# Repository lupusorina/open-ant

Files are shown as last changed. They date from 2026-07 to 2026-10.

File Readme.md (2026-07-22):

# Physical Ant

<p align="center">
  Ant walking demo
</p>
<p align="center">
  Video of a learned behaviour directly on hardware.
</p>

## Hardware.

The hardware is designed to be easy to build and use:
- single computer operation via USB, Python only, minimal dependencies (no embedded firmware / OS, networking, ROS...)
- no battery: continuous operation with wall adapter
- all COTS parts + 3D printed parts
- no soldering required
- no special tools required (only the standard hex drivers for M2, M2.5, and M3 screws which are 1.5mm, 2.0mm, and 2.5mm, respectively)

## Assembly video

[Watch the assembly video](https://www.youtube.com/watch?v=9aowd2JxAnE)

### Specs.

- hip range +/- 45deg
- knee range +/- 70deg

### Physical Ant platform, learning arena, and system overview.

<p align="center">
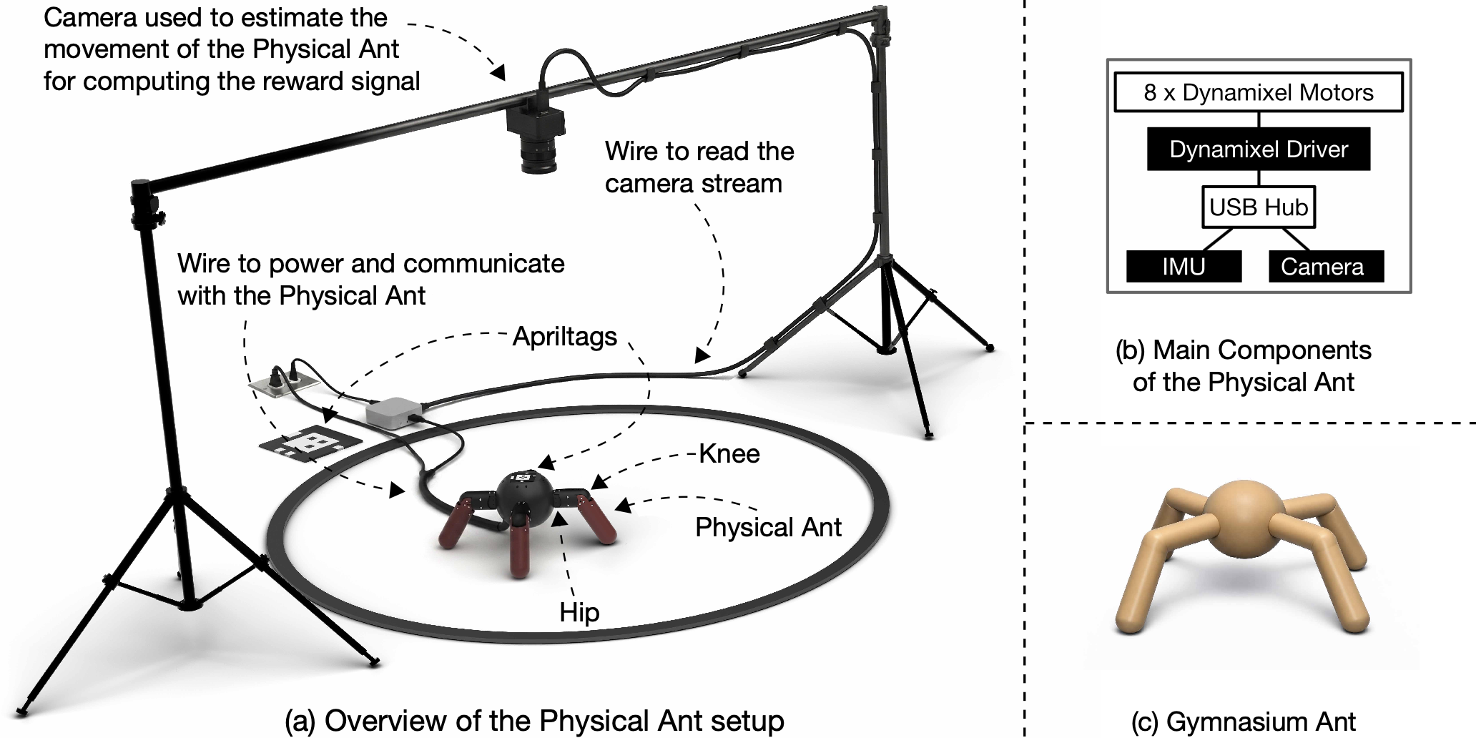
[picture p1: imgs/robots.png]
Robot setup
  
</p>
<p align="center">
  <b>Physical Ant platform, learning arena, and system overview.</b> (a) An overhead webcam tracks the fiducial markers to compute reward signals for locomotion tasks as well as the heading vector of the ant. The robot is connected by cables to AC power and to an external computer where the agent is running. (b) The main components of the Physical Ant. (c) The Gymnasium Ant, which was the inspiration for the Physical Ant.
</p>

#### Bill of Materials.

| Part Name | Quantity | Notes | Link | Price (March 2026) |
|---|---|---|---|---|
| Dynamixel XM430-W350-T | 4 | Main actuators  (incl.  180mm cable) | [Robotis](https://www.robotis.us/dynamixel-xm430-w350-t/) | $1241.56 (310.39 each) |
| Dynamixel XC430-W240-T | 4 | Main actuators  (incl.  180mm cable) | [Robotis](https://robotis.us/dynamixel-xc430-w240-t/) | $551.56 ($137.89 each) |
| HN11-I101 Set | 4 | Idler bearing | [Robotis](https://www.robotis.us/hn11-i101-set/) | $32.20 (8.05 each) |
| HN12-I101 Set | 4 | Idler bearing | [Robotis](https://www.robotis.us/hn12-i101-set/) | $81.88 (20.47 each)  |
| U2D2 Starter Set | 1 | Includes: USB to Dynamixel, Power Hub Board, 12V 5A Power Supply | [Robotis](https://www.robotis.us/dynamixel-starter-set-us/) | $68.66 |
| Kakute H7 Mini / TBS Lucid Freestyle mini | 1 | Quadcopter flight controller used as IMU (Any Betaflight compatible autopilot with 20x20mm mounts will work) | [getfpv](https://www.getfpv.com/tbs-lucid-freestyle-f4-mini-flight-controller-icm42688-20x20.html) | $51.99 |
| Cable Matters Ultra Mini USB Hub | 1 | 4 Port USB Hub | [Amazon](https://www.amazon.com/dp/B00PHPWLPA/) | $15.49 |
| Short USB-A to USB-C Cable | 1 | For autopilot (IMU) | [Amazon](https://www.amazon.com/dp/B01ASXBY62) | $11.96 |
| Short USB-A to micro-USB cable | 1 | For Dynamixel U2D2 | [Amazon](https://www.amazon.com/dp/B08BZD66H4?th=1) | $6.99 |
| USB-A extension cable | 1 | As tether for the robot | [Amazon](https://www.amazon.com/dp/B07ZV6FHWF/) | $5.99 |
| 12V 8A AC to DC Converter Power Adapter | 1 | Power adapter for the robot, to replace the one from the U2D2 starter kit | [Amazon](https://www.amazon.com/dp/B0F24DZ2SB?ref=ppx_yo2ov_dt_b_fed_asin_title&th=1) | $17.09 |
| Screw M2x4mm with socket head | 80 | Output shaft, 8 per motor, 3D print assembly | [McMaster](https://www.mcmaster.com/91290A012/) | $18.48 (pack of 100) |
| M2 washer | 64 | Output shaft | [McMaster](https://www.mcmaster.com/93475A195/)  | $1.78 (pack of 100) |
| Screw M2.5x16mm with socket head | 32 | motor mount, 4 per motor | [McMaster](https://www.mcmaster.com/91290a106/) | $12.81 (pack of 50)  |
| Screw M3x8mm with socket head | 6 | U2D2 power board mount + IMU | [McMaster](https://www.mcmaster.com/91290A113/) | $12.82 (pack of 100) |
| Nut M2 | 16 | 3D print assembly 4 per leg | [McMaster](https://www.mcmaster.com/91828A111/) | $6.75 (pack of 100)  |
| Nut M3 | 2 | U2D2 power board mount | [McMaster](https://www.mcmaster.com/91828A211/) | $5.2 (pack of 100)  |
| On-board camera and top-down camera for tracking | 2 | Logitech Brio 101 | [Logitech](https://www.logitech.com/en-us/shop/p/brio-100-webcam) | $79.98 (39.99 each) |
| 3D Printed Parts | - | STL files in `hardware/rev3`. Print all `leg` files 4x, others 1x. | - | - |
| **Total** | | | | **$2223.19** |

We recommend adding a heat sink to the knee actuators, for example this [one](https://www.amazon.com/dp/B08HLZWKYN?ref_=ppx_hzsearch_conn_dt_b_fed_asin_title_1&th=1)

### Dynamixel Setup (before assembling the robot!)

The Dynamixels should be configured to 1Mbaud and have their IDs changed to the following:

| Motor Position | Motor ID |
|---|---|
| Rear Right Hip | 10 |
| Rear Right Knee | 11 |
| Front Right Hip | 20 |
| Front Right Knee | 21 |
| Front Left Hip | 30 |
| Front Left Knee | 31 |
| Rear Left Hip | 40 |
| Rear Left Knee | 41 |

Use the following script to change the IDs of the motors, connecting one at a time.
```
python3 embodied_ant_env/dynamixel_change_id.py /dev/tty.usbserial-XXXXXXX <NEW_ID> 57600
```

When done, the following command will change the baudrate of all connected motors on the port to 1Mbaud.
```
python3 embodied_ant_env/dynamixel_change_baud.py /dev/tty.usbserial-XXXXXXX 1000000
```

## Software Setup

Create a virtual environment and install the dependencies. (python >= 3.10)
```
python3.12 -m venv ant_env
source ant_env/bin/activate
pip install -r requirements.txt
```

To create a new config file, run:
```
python3 embodied_ant_env/make_ant_config.py /dev/tty.usbserial-XXXXXXX <APRIL_TAG_ID>
```
which will create a new config file `ant<APRIL_TAG_ID>.json` in the current directory.

Next, edit the config file to specify imu port, camera id and fov.

### Possible signals

- Joint position
- Joint velocity
- Body angular rate
- Inertial up in body
- Commanded velocity in x and y

For reward: position of the body in x and y, and the angle of the body.

## Run the simulation

```
cd sim
python3 ant_mujoco.py
```

## Run SAC

for simulation:
```
cd agents/sac/
./run.sh sim
```

for hardware:
```
cd agents/sac/
./run.sh hw
```

## Run SARSA

for simulation:
```
cd agents/sarsa/
./run.sh sim
```

for hardware:
```
cd agents/sarsa/
./run.sh hw
```

## Frequently Asked Questions (FAQ)

### Q: The position of the ant flickers. What should I do?

The fiducial system is designed to be quite robust. If you encounter problems, make sure the markers are clearly visible and the camera exposure is configured properly (you can adjust exposure using LogiTune). 
Here are some suggestions:
* Depending on your environment, you may need to disable auto-exposure for more consistent detection.
* For the best performance, you should have the camera looking down at the playground.
* The origin marker should be mounted flat. Any warping can cause issues.
* Make sure to plot all system inputs and outputs to verify that the signals are clean. Learning from noisy or faulty signals can lead to poor results.

### Q: What’s the recommended way to specify a /dev/ device path in a JSON file on Ubuntu?

Use the persistent device path, for example:
```
/dev/serial/by-id/YYY
```

### Q: Will the screws become loose over time due to vibrations?

Yes, it can happen. For this, it is recommended to use Loctite Threadlocker. Ensure you don't apply too much because it can leak under the motor head and cause clogging.

### Q: How can we increase the friction on the lower legs?

We recommend 3D printing socks out of TPU.

### Q: There might be intermittent communication dropout. How is this addressed?

During long duration run-time learning experiments, we observed intermittent, very short communication dropouts. 
The power connection was modified to connect directly to the screw terminals on the control board rather than using the barrel connector. This eliminated the voltage drops caused by vibration-induced intermittent contact during learning experiments.

## Misc

if git push fails when adding large (~10MB) commits, try:
```
git config --global http.postBuffer 1048576000
```

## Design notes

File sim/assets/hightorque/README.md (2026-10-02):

# High Torque Robotics Mini Pi+ Pro

23-DoF humanoid, 14.72 kg, 0.367 m standing base height.
Product page: https://www.hightorquerobotics.com/mini-pi

## Provenance

Supplied by High Torque as `PiPlus_S_12L8A0G2H1W_LSE_260611`
(`PiPlus_S_12L8A0G2H1W_LSE_260611_with_armature.xml` plus `meshes/`). The code
in the name is the joint census: 12 leg, 8 arm, 0 gripper, 2 head, 1 waist.
No licence file accompanied the drop.

## What changed from the vendor file

`mini_pi.xml` is the vendor MJCF with five edits, all mechanical:

1. **The scene came out.** The vendor file carries its own floor plane, light,
   skybox and `<visual>`/`<statistic>` block. `ArenaBuilder` supplies those, and
   a second ground plane z-fights with the arena's. They now live in
   `scene.xml`, which `<include>`s the robot — the layout `booster_t1/` uses.
2. **The six floating-base motors came out.** The vendor block drove
   `floating_base_joint` with an `fx fy fz tx ty tz` wrench. That is a test
   harness: a free-floating robot in an arena has no such actuator, and the six
   would show up as extra `ctrl` slots.
3. **`meshdir` is `meshes`,** not `../meshes/` — the meshes sit beside the file
   here, not one level up as they did in the drop.
4. **Motor `ctrlrange` was aligned to the joint's own `actuatorfrcrange`,** per
   joint, taking the smaller of the two. The vendor authored them
   inconsistently: legs ±20 N·m under a ±21 joint rating, the waist ±30 under
   ±16, the arms ±20 under ±10. MuJoCo enforces the joint rating regardless, so
   the pair disagreeing only hides the real budget. `assets/manifests/mini_pi.yaml`
   carries the same numbers as `torque_limits`.
5. **A `home` keyframe was added.** The vendor file has none; see below.
6. **The visual meshes were decimated** from 1.23 M triangles to 178 k. See
   below.

Quote characters in `class='leg_motor'` attributes were normalised to double
quotes, and the model was renamed from the part number to `mini_pi_plus_pro`.

## The `home` stance

A 0.25 rad symmetric crouch (hip pitch −0.25, knee +0.50, ankle pitch −0.25
keeps the sole flat) with the arms hanging but abducted 0.20 rad at the
shoulder roll, base at z = 0.367 so the soles rest on z = 0.

Vendor joint names carry the segment, not the axis: `*_thigh_joint` is hip yaw
(axis z) and `*_calf_joint` is the knee (axis y).

The abduction is not cosmetic. At the vendor's all-zero pose the 0.03 m hand
spheres on `*_wrist_link` sit ~0.1 mm inside the thigh cylinders; 0.05 rad of
shoulder roll clears them and 0.20 leaves margin. Nothing resets to the all-zero
pose in normal use — `MdpEnv` writes the manifest `default_pose` — so this is
recorded rather than worked around.

## Where the PD gains came from

High Torque ships no trained controller with the model, so unlike
`assets/manifests/t1.yaml` there is no vendor RL config to copy. The manifest
gains are the smallest round values that hold `home` for 10 s under gravity,
measured on this MJCF with `install_pd_servos` at the training sim settings
(`sim_dt` 0.02/3, 30 iterations, `implicitfast`):

| hip/knee kp | kd  | 10 s base z | knee sag | peak τ |
|---:|----:|---:|---:|---:|
| 60 | 3.0 | 0.086 (down at 1.7 s) | — | 100% |
| 80 | 3.5 | 0.366 | 0.031 rad | 14% |
| **100** | **3.5** | **0.366** | **0.022 rad** | **12%** |
| 150 | 4.0 | 0.367 | 0.013 rad | 11% |
| 200 | 5.0 | 0.367 | 0.010 rad | 10% |

Below kp 80 an open-loop PD hold topples backwards over the heels — a balance
failure, not a numerical one: the CoM starts 9 mm ahead of the ankles with
67 mm of rear margin and walks out of the support polygon as the hips and
ankles sag. kp 100 was taken because its 0.022 rad knee sag is already under
the 0.030 the T1 manifest accepted, and ±10% (the `randomize_pd_gains` band)
still stands.

The measurement agrees with the vendor precedent: T1's hips are 200 kp at a
45 N·m rating, i.e. 4.4 kp per N·m, which at this robot's 20 N·m would give 89.
Ankles use T1's softer ratio (2.5 kp per N·m → 50), and arms and head scale the
same way off their own ratings.

## Known gaps

- `head_yaw_joint` and `head_pitch_joint` carry no `class`, so they alone have
  `armature="0"` — the vendor gave every other joint a rotor inertia. Left as
  authored: at the manifest's kp 10 the head tracks to 0.008 rad and never
  approaches its 3.6 N·m limit, so nothing yet depends on filling it in.
- The 28 mesh geoms are visual only (`contype=0 conaffinity=0 density=0`); all
  collision is primitive boxes, cylinders and spheres.
- There is no separate hand body — the forearm ends in a fixed `*_wrist_link` —
  so the wrist link is the hand for contact purposes and its 0.03 m sphere is
  the fist geom.

## Why the meshes were decimated

As supplied, the 28 visual meshes were 1.23 M triangles / 59 MB, compiling to a
**226 MB `MjModel`** against the Booster T1's 30 MB — seven times the weight of
any other robot here, for detail only a renderer sees.

They are now 178 k triangles / 8.7 MB, compiling to 36.9 MB — the T1's weight
class. Total mass is bit-identical at 14.71826 kg, because the mesh geoms carry
`density="0"` and every body has an explicit `<inertial>`, so triangle count
cannot touch the physics. The face budget is split across meshes by surface
area rather than capped per mesh: a flat cap starved the torso and visibly
flattened its curvature.

This is about repository weight and render cost. What made the size urgent was
training — a job randomizing model fields keeps one `MjModel` per environment,
so 512 envs wanted 113 GB and never reached iteration 1 — but that is now fixed
properly, by not building the visual assets into a scene nothing draws
(`ArenaBuilder(visual=False)` + `strip_visual_assets()`, see #319). Training
this robot at 512 envs holds 1.4 GB whatever the meshes weigh.

Reproduce from the vendor drop with any quadric decimator; the one used was
`fast-simplification`, installed into the worktree venv for the one-off pass and
deliberately NOT added to `pyproject.toml` — nothing at runtime reads it.

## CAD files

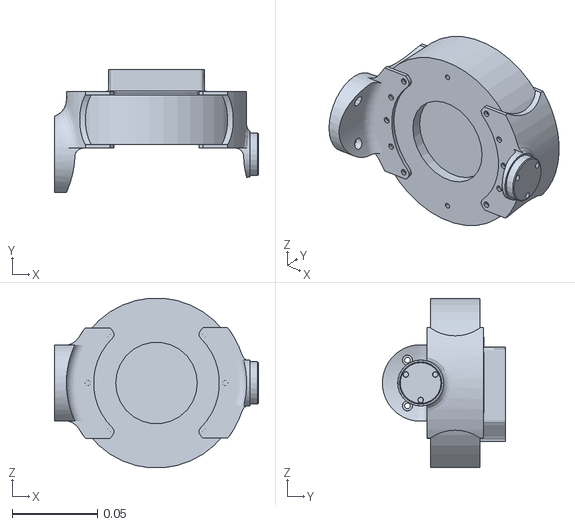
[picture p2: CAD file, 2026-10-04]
sim/assets/caltech_biped/meshes/R_SHOULDER.STL
0.12 x 0.0725 x 0.0997

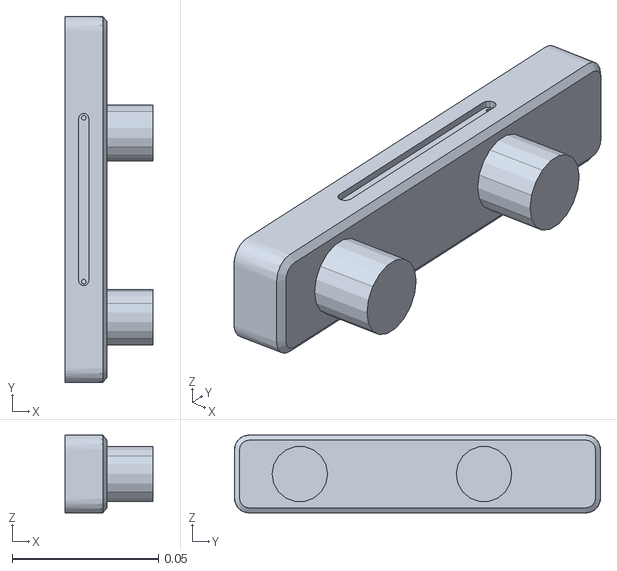
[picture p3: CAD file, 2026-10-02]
sim/assets/hightorque/meshes/camera_link.STL
0.0302 x 0.125 x 0.0266

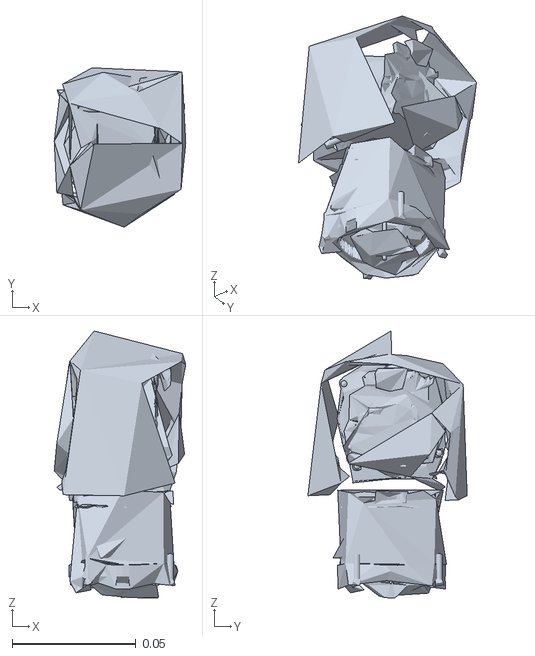
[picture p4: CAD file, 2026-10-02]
sim/assets/hightorque/meshes/r_shoulder_roll_link.STL
0.0531 x 0.0643 x 0.108

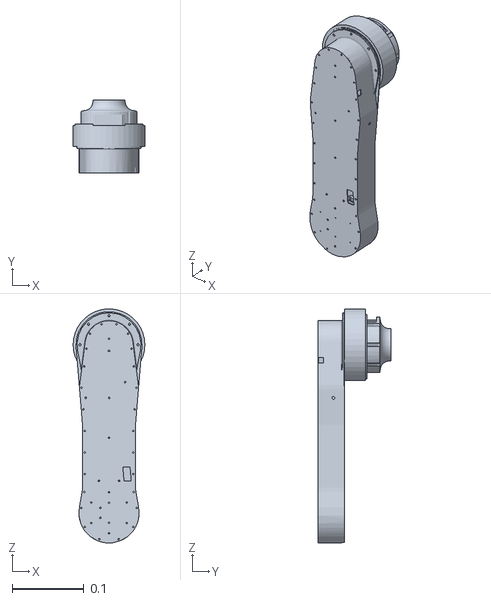
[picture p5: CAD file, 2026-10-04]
sim/assets/caltech_biped/meshes/R_UPPER_LEG.STL
0.1 x 0.102 x 0.326

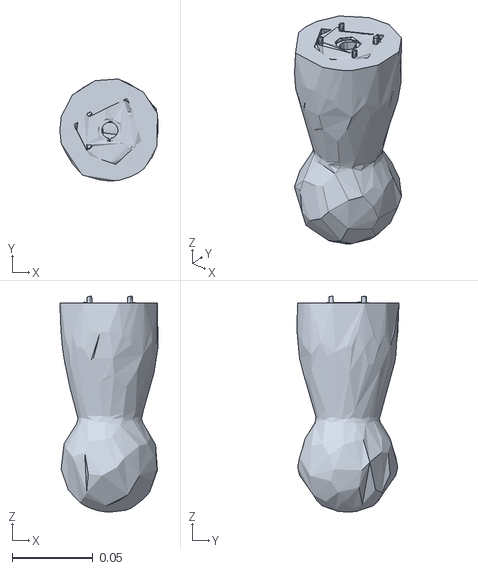
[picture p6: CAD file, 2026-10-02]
sim/assets/hightorque/meshes/l_wrist_link.STL
0.0607 x 0.063 x 0.133

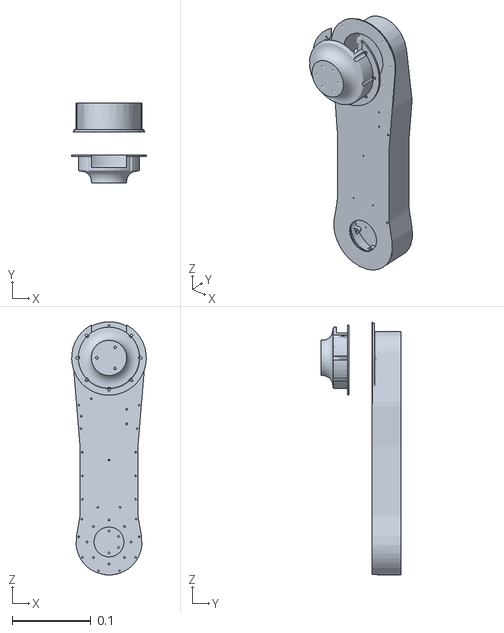
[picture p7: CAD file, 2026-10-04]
sim/assets/caltech_biped/meshes/L_UPPER_LEG.STL
0.0949 x 0.102 x 0.322

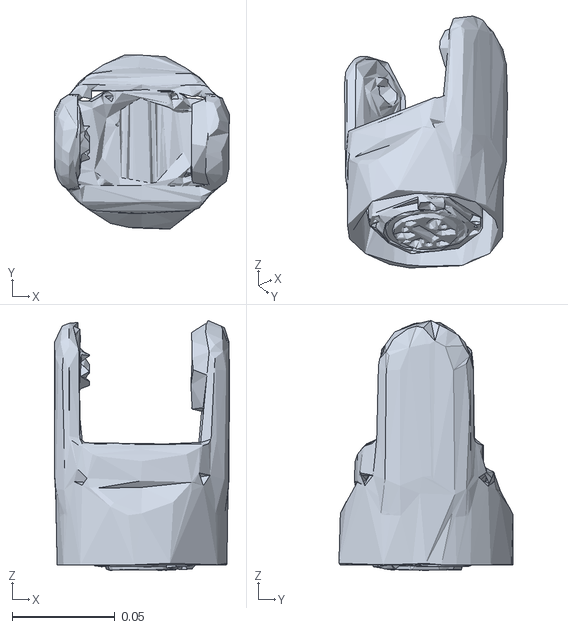
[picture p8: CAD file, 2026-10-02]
sim/assets/hightorque/meshes/r_hip_roll_link.STL
0.0853 x 0.0848 x 0.122

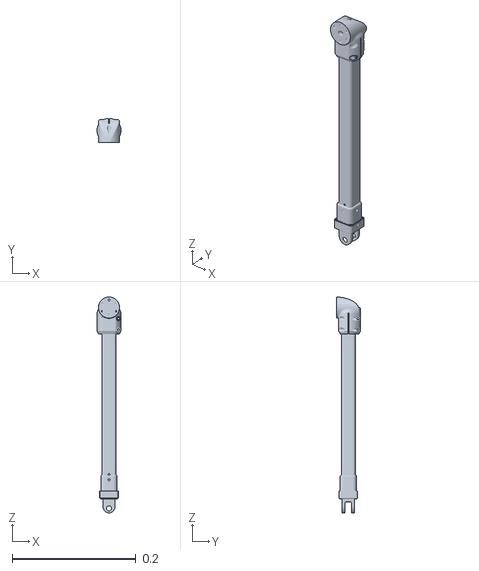
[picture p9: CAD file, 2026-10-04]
sim/assets/caltech_biped/meshes/R_LOWER_LEG.STL
0.039 x 0.0392 x 0.349

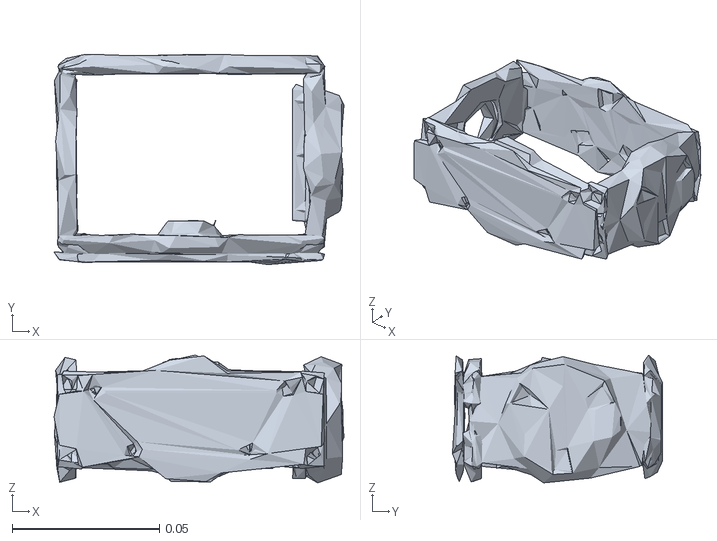
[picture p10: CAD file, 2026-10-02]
sim/assets/hightorque/meshes/l_ankle_pitch_link.STL
0.0985 x 0.0714 x 0.0434

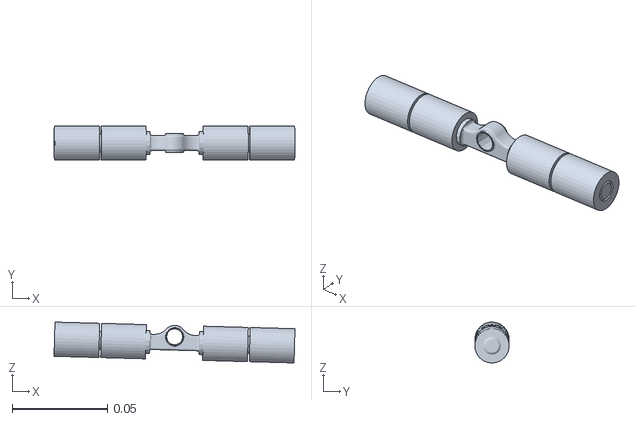
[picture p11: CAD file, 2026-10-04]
sim/assets/caltech_biped/meshes/L_FOOT.STL
0.126 x 0.018 x 0.0215

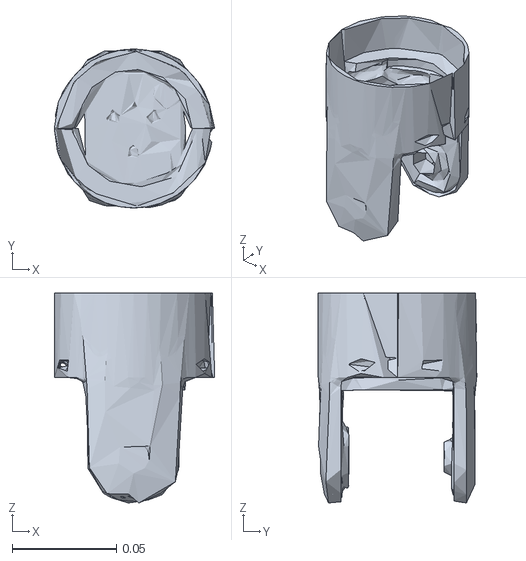
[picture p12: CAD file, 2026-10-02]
sim/assets/hightorque/meshes/r_upper_arm_link.STL
0.0768 x 0.076 x 0.101

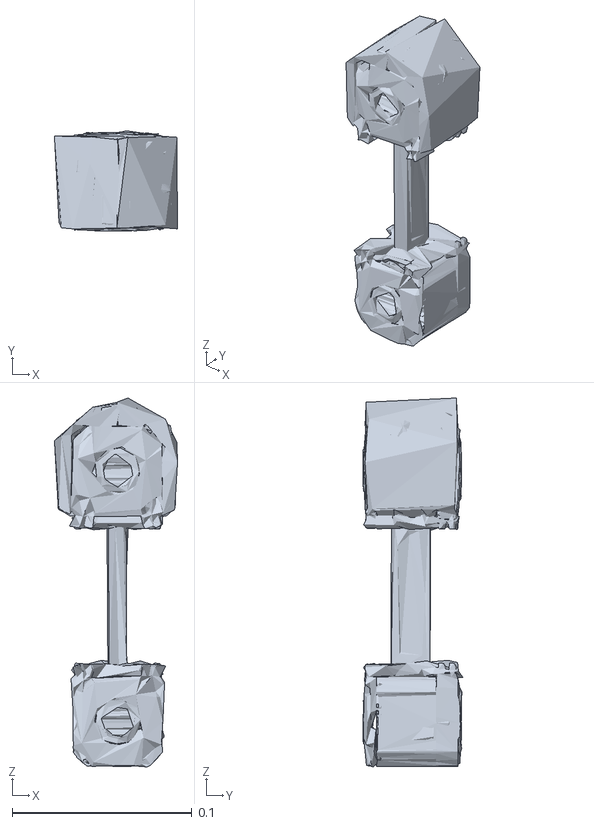
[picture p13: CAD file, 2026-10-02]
sim/assets/hightorque/meshes/l_calf_link.STL
0.0686 x 0.0559 x 0.206

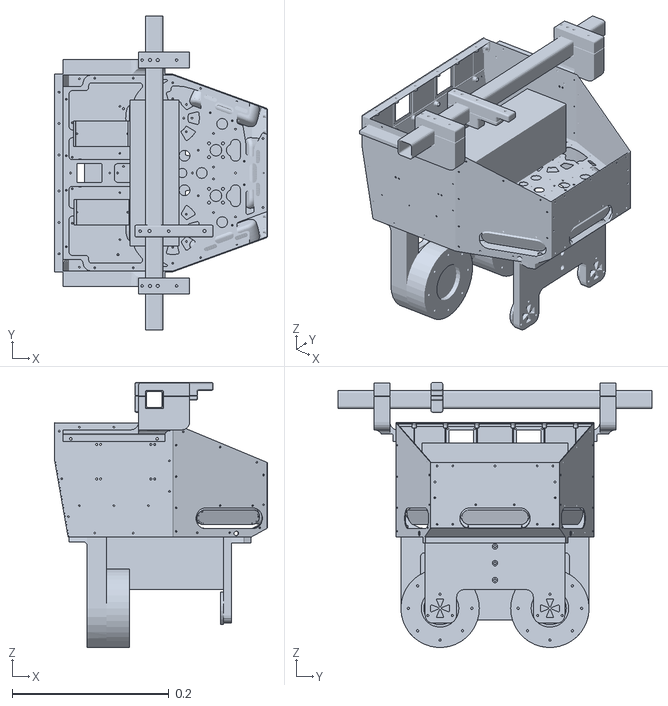
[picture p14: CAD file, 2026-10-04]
sim/assets/caltech_biped/meshes/base_link.STL
0.272 x 0.4 x 0.338

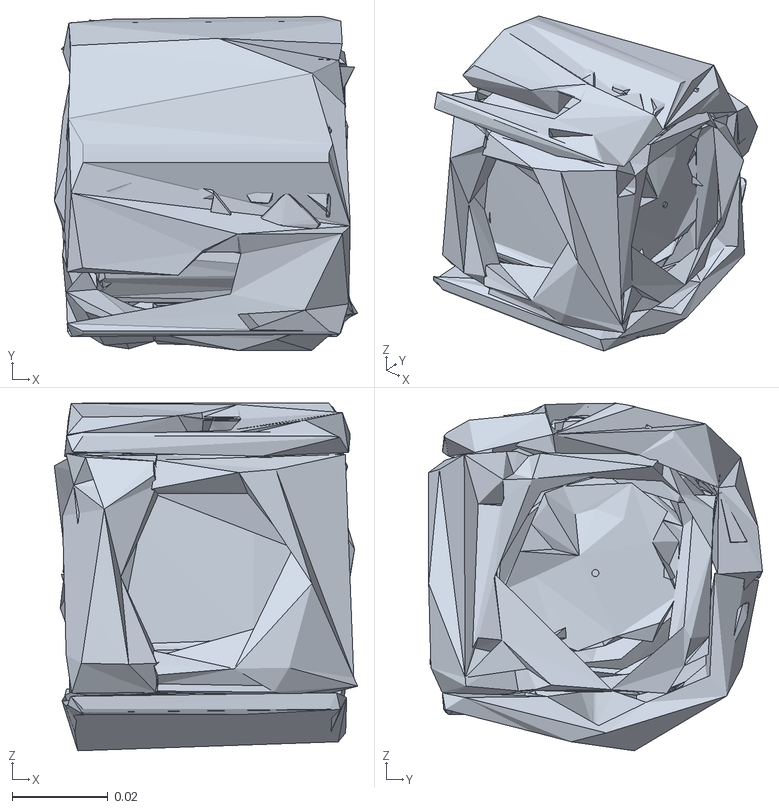
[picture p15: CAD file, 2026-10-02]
sim/assets/hightorque/meshes/l_hip_pitch_link.STL
0.0635 x 0.0699 x 0.0728

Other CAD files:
sim/assets/caltech_biped/meshes/L_SHOULDER.STL
sim/assets/caltech_biped/meshes/L_LOWER_LEG.STL
sim/assets/caltech_biped/meshes/R_FOOT.STL
sim/assets/hightorque/meshes/l_shoulder_roll_link.STL
sim/assets/hightorque/meshes/base_link.STL
sim/assets/hightorque/meshes/head_pitch_link.STL
sim/assets/hightorque/meshes/head_yaw_link.STL
sim/assets/hightorque/meshes/l_ankle_roll_link.STL
sim/assets/hightorque/meshes/l_elbow_link.STL
sim/assets/hightorque/meshes/l_hip_roll_link.STL
sim/assets/hightorque/meshes/l_shoulder_pitch_link.STL
sim/assets/hightorque/meshes/l_thigh_link.STL
sim/assets/hightorque/meshes/l_upper_arm_link.STL
sim/assets/hightorque/meshes/r_ankle_pitch_link.STL
sim/assets/hightorque/meshes/r_ankle_roll_link.STL
sim/assets/hightorque/meshes/r_calf_link.STL
sim/assets/hightorque/meshes/r_elbow_link.STL
sim/assets/hightorque/meshes/r_hip_pitch_link.STL
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

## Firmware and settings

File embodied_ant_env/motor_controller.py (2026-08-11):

import dynamixel_sdk
import numpy as np
import time
import logging
import serial


class MotorControllerError(Exception):
    pass


logger = logging.getLogger(__name__)
if not logger.handlers:
    logger.addHandler(logging.FileHandler('motor_controller.log'))
    logger.addHandler(logging.StreamHandler())


class MotorController:
    ADDR_TORQUE_ENABLE = 64
    ADDR_GOAL_POSITION = 116
    ADDR_PRESENT_LOAD = 126
    ADDR_PRESENT_VELOCITY = 128
    ADDR_PRESENT_POSITION = 132
    ADDR_PRESENT_TEMPERATURE = 146
    ADDR_OPERATING_MODE = 11
    ADDR_HARDWARE_ERROR_STATUS = 70
    ADDR_PWM_LIMIT = 36
    ADDR_SHUTDOWN = 63

    def __init__(self, port, motor_list, baudrate=1000000):
        self.port = dynamixel_sdk.PortHandler(port)
        self.packet = dynamixel_sdk.PacketHandler(2.0)
        self.logger = logger

        if not self.port.openPort():
            self.logger.error("Failed to open port %s", port)
            raise MotorControllerError(f"Failed to open port {port}")
        if not self.port.setBaudRate(baudrate):
            self.logger.error("Failed to set baudrate %s on port %s", baudrate, port)
            raise MotorControllerError(f"Failed to set baudrate {baudrate} on port {port}")
        self.motor_list = motor_list
        self.find_offset()

    def __del__(self):
        try:
            self.disable()
        except Exception as e:
            self.logger.error(f"Error disabling motors in __del__: {e}")

    def _reopen_port(self):
        # Close and re-open the port to clear the buffer. Tolerant of a missing
        # device (e.g. unplugged USB): a failed re-open raises MotorControllerError
        # so callers only ever handle one exception type.
        try:
            self.port.closePort()
        except (OSError, serial.SerialException):
            pass
        try:
            if not self.port.openPort():
                raise MotorControllerError("Failed to re-open port")
        except (OSError, serial.SerialException) as e:
            raise MotorControllerError(f"Failed to re-open port: {e}")

    def sync_read_rxtx_retry(self, sync_read_obj, num_retries=3):
        try:
            for attempt in range(num_retries):
                dxl_comm_result = sync_read_obj.txRxPacket()
                if dxl_comm_result == dynamixel_sdk.COMM_SUCCESS:
                    return dxl_comm_result
                self.logger.warning("sync_read attempt %d/%d failed: %s; retrying...",
                            attempt, num_retries, dxl_comm_result)
                self._reopen_port()
            self.logger.error("sync_read failed after %d attempts: %s",
                        num_retries, dxl_comm_result)
            raise MotorControllerError(f"Failed to perform sync read: {dxl_comm_result}")
        except (OSError, serial.SerialException) as e:
            self.logger.error(f"Serial exception: {e}")
            raise MotorControllerError(f"Serial exception: {e}")

    def _check_result(self, res, err, motor_id, what):
        # res is the comm result; err is the servo status/hardware error byte.
        if res != dynamixel_sdk.COMM_SUCCESS:
            msg = f"Failed to {what} on motor {motor_id}: {self.packet.getTxRxResult(res)}"
            self.logger.error(msg)
            raise MotorControllerError(msg)
        if err != 0:
            msg = (f"Failed to {what} on motor {motor_id}: "
                   f"0x{err:02X} {self.packet.getRxPacketError(err)}")
            self.logger.error(msg)
            raise MotorControllerError(msg)

    def find_offset(self):
        self.offset = [0] * len(self.motor_list)
        initial_positions = self.get_feedback()[0]  # read positions with offset 0
        offset = []
        for motor, pos in zip(self.motor_list, initial_positions):
            center = (motor['min_position'] + motor['max_position']) / 2 + motor['offset']
            delta = pos - center
            offset.append(np.round(delta / (2 * np.pi)) * 2 * np.pi + motor['offset'])
        self.offset = offset

    def enable(self):
        for motor in self.motor_list:
            res, err = self.packet.write1ByteTxRx(self.port, motor['id'], self.ADDR_TORQUE_ENABLE, 0)
            self._check_result(res, err, motor['id'], "disable torque")
            res, err = self.packet.write1ByteTxRx(self.port, motor['id'], self.ADDR_OPERATING_MODE, 4) # multi-turn mode
            self._check_result(res, err, motor['id'], "set operating mode")
            res, err = self.packet.write2ByteTxRx(self.port, motor['id'], self.ADDR_PWM_LIMIT, int(50/0.113)) # set PWM limit
            self._check_result(res, err, motor['id'], "set PWM limit")
            val = (1 << 0) | (1 << 2) | (1 << 3) | (1 << 4) | (1 << 5) # faults: voltage, overheat, encoder, electrical, overload
            res, err = self.packet.write1ByteTxRx(self.port, motor['id'], self.ADDR_SHUTDOWN, val) # set fault shutdown
            self._check_result(res, err, motor['id'], "set fault shutdown")
            # all settings must be changed before enabling torque
            res, err = self.packet.write1ByteTxRx(self.port, motor['id'], self.ADDR_TORQUE_ENABLE, 1)
            self._check_result(res, err, motor['id'], "enable torque")
        self.find_offset()

    def disable(self):
        for motor in self.motor_list:
            res, err = self.packet.write1ByteTxRx(self.port, motor['id'], self.ADDR_TORQUE_ENABLE, 0)
            self._check_result(res, err, motor['id'], "disable torque")

    def pos_to_dxl_units(self, pos):
        return int((pos) * 4095 / (2 * np.pi))

    def dxl_units_to_pos(self, dxl_units):
        return (dxl_units / 4095 * 2 * np.pi)

    def dxl_units_to_vel(self, dxl_units):
        return dxl_units * 2 * np.pi * 0.229 / 60

    def interpret_int_as_signed(self, value, num_bits):
        if value & (1 << (num_bits - 1)):
            return value - (1 << num_bits)
        return value

    def set_positions(self, positions):
        try:
            sync_write = dynamixel_sdk.GroupSyncWrite(self.port, self.packet, self.ADDR_GOAL_POSITION, 4)
            for pos, motor, offset in zip(positions, self.motor_list, self.offset):
                data = [0] * 4
                pos = np.clip(pos, motor['min_position'], motor['max_position'])
                pos_dxl_units = self.pos_to_dxl_units(pos + offset)
                data[0] = pos_dxl_units & 0xFF
                data[1] = (pos_dxl_units >> 8) & 0xFF
                data[2] = (pos_dxl_units >> 16) & 0xFF
                data[3] = (pos_dxl_units >> 24) & 0xFF
                sync_write.addParam(motor['id'], data)
            dxl_comm_result = sync_write.txPacket()
            if dxl_comm_result != dynamixel_sdk.COMM_SUCCESS:
                self.logger.error(f"Failed to set positions: {self.packet.getTxRxResult(dxl_comm_result)}")
                raise MotorControllerError(f"Failed to set positions: {self.packet.getTxRxResult(dxl_comm_result)}")
            sync_write.clearParam()
        except (OSError, serial.SerialException) as e:
            self.logger.error(f"Serial exception: {e}")
            raise MotorControllerError(f"Serial exception: {e}")

    def get_feedback_raw(self):
        sync_read = dynamixel_sdk.GroupSyncRead(self.port, self.packet, self.ADDR_PRESENT_LOAD, 2 + 4 + 4)
        for motor in self.motor_list:
            sync_read.addParam(motor['id'])
        self.sync_read_rxtx_retry(sync_read)
        positions = []
        velocities = []
        loads = []
        for motor in self.motor_list:
            if sync_read.isAvailable(motor['id'], self.ADDR_PRESENT_POSITION, 4):
                data = sync_read.getData(motor['id'], self.ADDR_PRESENT_POSITION, 4)
                positions.append(self.interpret_int_as_signed(data, 32))
            else:
                self.logger.error(f"Motor {motor['id']} not found in sync read")
                raise MotorControllerError(f"Motor {motor['id']} not found in sync read")
            if sync_read.isAvailable(motor['id'], self.ADDR_PRESENT_VELOCITY, 4):
                data = sync_read.getData(motor['id'], self.ADDR_PRESENT_VELOCITY, 4)
                velocities.append(self.interpret_int_as_signed(data, 32))
            else:
                self.logger.error(f"Motor {motor['id']} not found in sync read")
                raise MotorControllerError(f"Motor {motor['id']} not found in sync read")
            if sync_read.isAvailable(motor['id'], self.ADDR_PRESENT_LOAD, 2):
                data = sync_read.getData(motor['id'], self.ADDR_PRESENT_LOAD, 2)
                loads.append(self.interpret_int_as_signed(data, 16))
            else:
                self.logger.error(f"Motor {motor['id']} not found in sync read")
                raise MotorControllerError(f"Motor {motor['id']} not found in sync read")
        sync_read.clearParam()
        return positions, velocities, loads

    def get_feedback(self):
        positions_raw, velocities_raw, loads_raw = self.get_feedback_raw()
        positions = [self.dxl_units_to_pos(pos) for pos in positions_raw]
        positions = [pos - offset for pos, offset in zip(positions, self.offset)]
        velocities = [self.dxl_units_to_vel(vel) for vel in velocities_raw]
        loads = [load/1000 for load in loads_raw]
        return positions, velocities, loads

    def get_error_string(self, hw_error_status):
        errors = []
        if hw_error_status & (1 << 0):
            errors.append("Input voltage")
        if hw_error_status & (1 << 2):
            errors.append("Overheat")
        if hw_error_status & (1 << 3):
            errors.append("Encoder")
        if hw_error_status & (1 << 4):
            errors.append("Electrical")
        if hw_error_status & (1 << 5):
            errors.append("Overload")
        return ", ".join(errors)

    def check_errors(self):
        sync_read = dynamixel_sdk.GroupSyncRead(self.port, self.packet, self.ADDR_HARDWARE_ERROR_STATUS, 1)
        for motor in self.motor_list:
            sync_read.addParam(motor['id'])
        self.sync_read_rxtx_retry(sync_read)
        errors = []
        for motor in self.motor_list:
            if sync_read.isAvailable(motor['id'], self.ADDR_HARDWARE_ERROR_STATUS, 1):
                data = sync_read.getData(motor['id'], self.ADDR_HARDWARE_ERROR_STATUS, 1)
                # if data & (0xFF - (1 << 5)) != 0: # ignore overload error
                if data != 0:
                    errors.append((motor['id'], data, f"motor {motor['id']}: 0x{data:02X} errors: {self.get_error_string(data)}"))
                    self.logger.error(f"Motor {motor['id']} has errors: {self.get_error_string(data)}")
            else:
                self.logger.error(f"Motor {motor['id']} not found in sync read")
                raise MotorControllerError(f"Motor {motor['id']} not found in sync read")
        return errors

    def _recover_once(self):
        self._reopen_port()
        for motor in self.motor_list:
            res, err = self.packet.reboot(self.port, motor['id'])
            self._check_result(res, err, motor['id'], "reboot")
            time.sleep(0.1)
        self.enable()
        errors = self.check_errors()
        if len(errors) > 0:
            raise MotorControllerError(f"Errors remain after recovery: {errors}")

    def recover_from_error(self, retry_interval=0.1):
        # Block until recovery succeeds
        attempt = 0
        while True:
            attempt += 1
            try:
                self._recover_once()
                self.logger.info("Motor recovery succeeded after %d attempt(s)", attempt)
                return
            except (MotorControllerError, OSError, serial.SerialException) as e:
                self.logger.warning("Motor recovery attempt %d failed: %s; retrying in %.3fs",
                                    attempt, e, retry_interval)
                time.sleep(retry_interval)

    def get_temperature(self):
        sync_read = dynamixel_sdk.GroupSyncRead(self.port, self.packet, self.ADDR_PRESENT_TEMPERATURE, 1)
        for motor in self.motor_list:
            sync_read.addParam(motor['id'])
        self.sync_read_rxtx_retry(sync_read)
        temperatures = []
        for motor in self.motor_list:
            if sync_read.isAvailable(motor['id'], self.ADDR_PRESENT_TEMPERATURE, 1):
                data = sync_read.getData(motor['id'], self.ADDR_PRESENT_TEMPERATURE, 1)
                temperatures.append(data)
            else:
                self.logger.error(f"Motor {motor['id']} not found in sync read")
                raise MotorControllerError(f"Motor {motor['id']} not found in sync read")
        sync_read.clearParam()
        return temperatures


if __name__ == "__main__":
    import json
    import sys
    import time
    # drv = MotorController(port=sys.argv[1], motor_list=[
    #     {'id': 10, 'min_position': -0.79, 'max_position': 0.79, 'offset': 0.79},
    #     {'id': 11, 'min_position': -0.79, 'max_position': 0.79, 'offset': 0.79},
    #     {'id': 20, 'min_position': -0.79, 'max_position': 0.79, 'offset': -0.79},
    #     {'id': 21, 'min_position': -0.79, 'max_position': 0.79, 'offset': 0.79},
    #     {'id': 30, 'min_position': -0.79, 'max_position': 0.79, 'offset': 0.79},
    #     {'id': 31, 'min_position': -0.79, 'max_position': 0.79, 'offset': 0.79},
    #     {'id': 40, 'min_position': -0.79, 'max_position': 0.79, 'offset': -0.79},
    #     {'id': 41, 'min_position': -0.79, 'max_position': 0.79, 'offset': -0.79},
    # ])
    cfg = json.load(open(sys.argv[1]))
    drv = MotorController(port=cfg['motor_port'], motor_list=cfg['motor_list'])
    drv.disable()
    drv.enable()
    while True:
        t_start = time.time()
        pos, vel, load = drv.get_feedback()
        print(pos)
        # time.sleep(0.01)
        drv.set_positions([np.sin(time.time())*0.8]*len(drv.motor_list))
        t_end = time.time()
        print(f"Time taken: {t_end - t_start:.3f}s")
        time.sleep(0.001)

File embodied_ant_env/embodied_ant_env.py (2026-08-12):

import time
import threading
import numpy as np
import gymnasium as gym
from gymnasium import spaces
from gymnasium.spaces import Box
from collections import defaultdict

from imu_msp import IMU_MSP
from apriltag_tracking import VisionTracker, show_image
from motor_controller import MotorController, MotorControllerError

class IMUError(Exception):
    pass


class CameraError(Exception):
    pass


class ForwardTask:
    def __init__(self, action_cost_weight=0.0):
        self.action_cost_weight = action_cost_weight
        self.last_pos = None
        self.last_action = np.zeros(8)
        self.reward_direction_I = np.array([1, 0])
        self.observation_space = spaces.Box(low=-1.5, high=1.5, shape=(24,), dtype=np.float32)
        self.previous_pos_timestamp = None

    def reset(self, info, action=np.zeros(8)):
        self.last_pos = None
        self.previous_pos_timestamp = None
        return self(info, action)

    def __call__(self, info, action):
        pos = np.array([info['current_x_position'], info['current_y_position']])
        pos_timestamp = info['position_timestamp']
        if self.last_pos is None:
            self.last_pos = pos
            progress = 0.0
        else:
            progress = (pos - self.last_pos)[0]

        if self.previous_pos_timestamp is None:
            self.previous_pos_timestamp = pos_timestamp

        if pos_timestamp == self.previous_pos_timestamp:
            print('Warning!! The frames did not update!')

        cost_action = np.sum(np.square(self.last_action - action)) * self.action_cost_weight
        self.last_pos = pos
        self.previous_pos_timestamp = pos_timestamp
        self.last_action = action.copy()
        terminated = False
        truncated = False

        reward = progress - cost_action
        info['reward_direction_I'] = self.reward_direction_I
        info['original_reward'] = reward
        info['actions'] = action
        observation = np.concatenate([
            info['joint_positions'],
            info['joint_velocities'],
            info['heading_vector'],
            info['ax'],
            info['ay'],
            info['az'],
            info['wx'],
            info['wy'],
            info['wz'],
        ], axis=None)
        return observation, reward, terminated, truncated


class BackAndForthTask:
    def __init__(self, action_cost_weight=0.0, radius=1.0, origin=np.array([0, 0])):
        self.action_cost_weight = action_cost_weight
        self.last_pos = None
        self.reward_direction_I = np.array([1, 0])
        self.last_action = np.zeros(8)
        self.previous_pos_timestamp = None
        self.observation_space = spaces.Box(low=-1.5, high=1.5, shape=(24,), dtype=np.float32)
        self.radius = radius
        self.origin = origin

    def reset(self, info, action=np.zeros(8)):
        self.last_pos = None
        self.previous_pos_timestamp = None
        th = np.random.uniform(-np.pi, np.pi)
        self.reward_direction_I = np.array([np.cos(th), np.sin(th)])
        return self(info, action)

    def __call__(self, info, action):
        pos = np.array([info['current_x_position'], info['current_y_position']])
        pos_timestamp = info['position_timestamp']
        # Bounce back on the circle edge.
        if np.dot(pos - self.origin, self.reward_direction_I) > 0 and np.linalg.norm(pos - self.origin) > self.radius:
            self.reward_direction_I = self.origin - pos
            self.reward_direction_I /= np.linalg.norm(self.reward_direction_I)

        if self.last_pos is None:
            self.last_pos = pos
            progress = 0.0
        else:
            progress = np.dot(pos - self.last_pos, self.reward_direction_I)

        if self.previous_pos_timestamp is None:
            self.previous_pos_timestamp = pos_timestamp

        if pos_timestamp == self.previous_pos_timestamp:
            print("Reward", progress)
            print('Warning!! The frames did not update!')

        cost_action = np.sum(np.square(self.last_action - action)) * self.action_cost_weight
        self.last_pos = pos
        self.previous_pos_timestamp = pos_timestamp
        self.last_action = action.copy()
        terminated = False
        truncated = False

        reward = progress - cost_action
        info['reward_direction_I'] = self.reward_direction_I
        info['reward_direction_I_x'] = self.reward_direction_I[0]
        info['reward_direction_I_y'] = self.reward_direction_I[1]

        heading_perp = np.array([-info['heading_vector'][1], info['heading_vector'][0]])
        reward_direction_B = np.array([np.dot(info['reward_direction_I'], info['heading_vector']),
                             np.dot(info['reward_direction_I'], heading_perp)])

        info['reward_direction_B_x'] = reward_direction_B[0]
        info['reward_direction_B_y'] = reward_direction_B[1]
        info['original_reward'] = reward
        info['actions'] = action
        observation = np.concatenate([
            info['joint_positions'],
            info['joint_velocities'],
            reward_direction_B,
            info['ax'],
            info['ay'],
            info['az'],
            info['wx'],
            info['wy'],
            info['wz'],
        ], axis=None)

        return observation, reward, terminated, truncated
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

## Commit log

2026-05-21 fix torch version for driver
2026-07-23 changed default spi to 1536
2026-08-12 increase out of frame boundary
2026-09-16 quantile critic continuous stochastic actor in actor-critic framework
2026-10-03 caltech biped
    [L_FOOT.STL, L_LOWER_LEG.STL, L_SHOULDER.STL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]
2026-10-22 Update Readme with power connection and USB cable notes
    Added information about USB cable failure and its impact on communication dropouts.
2026-10-22 Fix link for M2x4mm screw in Readme
    Updated the link for the M2x4mm screw to the correct product.
2026-10-22 Update USB cable advice and component security tips
    Added recommendations for cable strain relief and securing components inside the ant.
2026-10-22 Update hardware list in Readme.md
    Updated the quantity and description for M3x8mm screws and added a new M3x8mm screw type for IMU.
2026-10-22 specify plastic screws
